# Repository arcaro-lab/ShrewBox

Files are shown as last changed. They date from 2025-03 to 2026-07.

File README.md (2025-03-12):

# ShrewBox: Modular Behavior Box for Tree Shrew and Other Small Animal Experiments

## Overview
We developed a low-cost, customizable behavior box designed for conducting animal experiments, particularly in tree shrews and other small animals. This modular platform allows precise control over stimulus presentation and reward delivery while animals maintain access to their home cage. It expands the methodological toolkit for investigating complex behaviors in a controlled yet naturalistic environment.

## Features
- **Precision Reward Delivery**: Stepper motors provide fine control (0.11° step rotation) of reward amounts with individual channel control, reducing wear and tear. These are downsized versions of the wonderful pumps developed by the Pachter Lab (https://github.com/pachterlab/pegasus).
- **Adjustable Visual Display**: Can accomodate 14"-15" monitors allowing for  adjustable viewing angles and distances ensure optimal stimulus presentation.
- **Capacitive Touch Pads**: Enables animals to indicate choices while maintaining gaze at the screen, allowing precise tracking of body position.
- **Compact and Integrated**: Raspberry Pi 4 replaces external computers, reducing footprint and minimizing the number of Arduinos and wires. All components are mounted directly on the box.
- **Customizable Box Panels**: Laser-cut and 3D-printable components simplify assembly while enabling modular expansion.
- **Scalability**: Daisy chain multiple behavior boxes to the same power source for simultaneous experiments.
- **Open-Source Experiment Control**: Runs on Python-based PsychoPy, making it accessible and customizable.
- **Integrated Weight Monitoring**: Onboard weight scale for tracking animal weight in real time.

## Assembly and Usage
We are currently developing detailed written instructions and instructional videos for assembling and using the behavior box. These will be available in this repository soon. In the meantime, groups interested in the behavior box should reach out to us directly for more information.

Currently, this repository provides:
- 3D files for 3D printing
- Files for laser-cut panels
- Bill of materials
- Source code for the capacitive touch sensor
- Source code for controlling Arduinos that interface with the stepper motor and weight sensors

## Photo
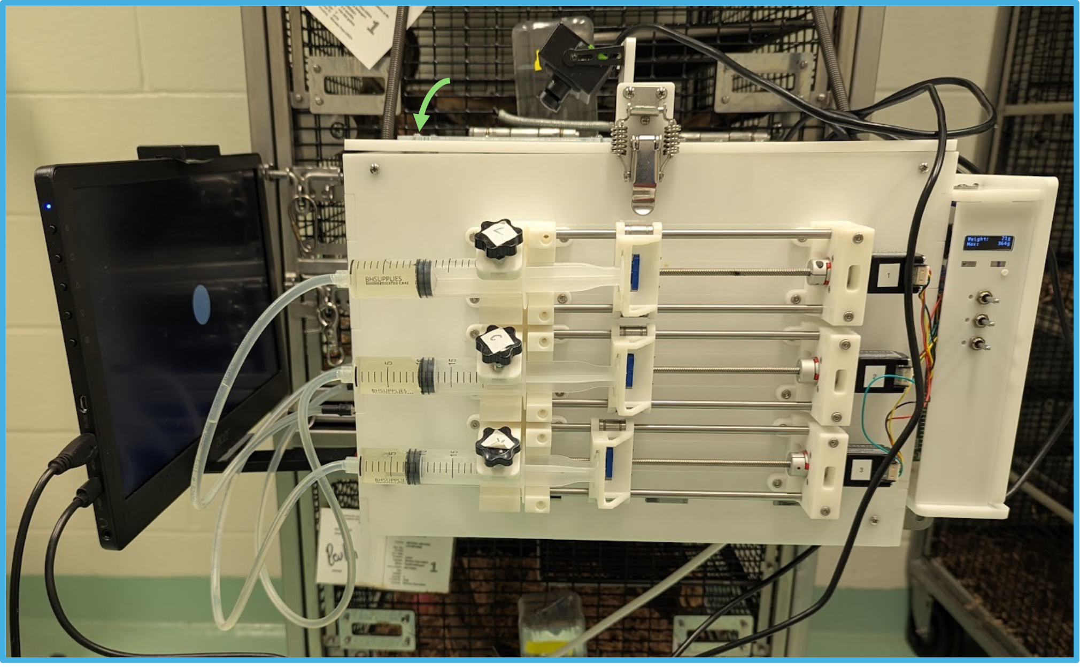
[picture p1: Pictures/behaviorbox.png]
Behavior Box


## Contributions
This project is open-source, and we welcome contributions! If you have improvements or modifications, feel free to submit a pull request or open an issue.

---
For inquiries, please contact the [Arcaro Lab](https://arcarolab.com).

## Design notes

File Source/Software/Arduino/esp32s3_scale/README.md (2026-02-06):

# ESP32-S3 Digital Scale (NAU7802 + TFT Feather)

This project is an update for a legacy  
**Teensy 3.2 + TeensyView + load cell** digital scale, rewritten for the:

- **Adafruit TFT Feather ESP32-S3 (Reverse)**
- **NAU7802 24-bit ADC**
- **1 kg load cell**

It reads the load cell via the NAU7802, converts the value to **grams**, displays
the result on the built‑in TFT, and streams measurements over **USB Serial**.
A hardware button on **D0** is used for **tare**.

---

## Features

- 📏 24‑bit load cell reading via **NAU7802**
- ⚖️ Linear calibration: tare offset + scale factor
- 📺 Live weight + max weight display on TFT
- 🧮 Exponential smoothing (similar feel to the Teensy implementation)
- 🔘 **D1 button** for tare (INPUT_PULLDOWM, active‑high)
- 💻 USB Serial output for logging
- ⌨️ Serial commands compatible with the Teensy workflow

---

## Hardware

### Required
- Adafruit **TFT Feather ESP32‑S3 (Reverse)**
- **NAU7802** load cell amplifier
- 1 kg (or similar) load cell (Wheatstone bridge)

### Connections
| Signal | ESP32‑S3 Feather |
|---|---|
| NAU7802 SDA | SDA |
| NAU7802 SCL | SCL |
| NAU7802 VCC | 3V |
| NAU7802 GND | GND |
| Tare Button | D1 → GND |

> The NAU7802 uses I²C. No extra pins are required.

---

## Software Dependencies

Install the following libraries via **Arduino Library Manager**:

- **Adafruit NAU7802**
- **Adafruit GFX Library**
- **Adafruit ST7789**
- **Adafruit BusIO**

Board package:
- **Adafruit ESP32 Boards**  
  (select *Adafruit Feather ESP32‑S3 TFT*)

---

## Serial Commands

| Command | Action |
|---|---|
| `t` | Tare (zero the scale) |
| `s` | Start / stop streaming |

Baud rate: **115200**

---

## Calibration (Important)

Calibration is intentionally simple.

1. Upload the sketch
2. Open **Serial Monitor**
3. Ensure the scale is empty
4. Press **D1** (or send `t`) to tare
5. Place a **known weight** (e.g. 100 g)
6. Observe the printed values:
   ```
   RAW=xxxxx, TARE=yyyyy
   ```
7. Compute:
   ```
   CAL_G_PER_COUNT = known_grams / (RAW - TARE)
   ```
8. Edit the sketch:
   ```cpp
   static float CAL_G_PER_COUNT = 0.00012345;
   ```
9. Re-upload

---

## Display

The TFT shows:
- **Current weight (g)**
- **Maximum weight recorded**
- Tare offset and calibration factor (debug)

Update rate: ~4 Hz (configurable)

---

## Notes

- If readings appear inverted, either:
  - swap the load cell signal wires, or
  - leave wiring as-is (the code displays absolute weight)
- The smoothing factor can be adjusted:
  ```cpp
  static const float EMA_ALPHA = 0.20f;
  ```
- Power is fully USB-based

---

## License

MIT License  
Use freely for research, teaching, and lab instrumentation.

---

## Acknowledgments

- Adafruit NAU7802 driver
- Original Teensy-based scale implementation

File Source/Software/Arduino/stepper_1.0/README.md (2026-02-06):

# 3-Channel Stepper Motor Controller (TMC2209 + Serial)

This project implements a **3-stepper-motor controller** using **TMC2209 step/dir drivers**, controlled either by **physical toggle switches** or by **serial commands** over USB.

It is designed for **simple, reliable lab use**, supporting both manual jogging and scripted motion from MATLAB, Python, or a serial terminal.

---

## Features

- Control **3 independent stepper motors**
- Dual control modes:
  - **Manual toggle switches** (LEFT / RIGHT per motor)
  - **Serial control** over USB
- Simple human-readable command format  
  (`S1,0,100`, `S2,1,200,400`)
- Compatible with **TMC2209 in STEP/DIR mode**
- Deterministic blocking motion (easy to reason about)

---

## Hardware Assumptions

- Microcontroller with USB serial (nRF52 / TinyUSB compatible)
- Stepper drivers: **TMC2209** (standalone STEP/DIR mode)
- Enable pin is **active-LOW**
- Toggle switches wired to **GND**, using `INPUT_PULLUP`

---

## Pin Mapping

### Stepper Drivers

| Motor | DIR | STEP | EN |
|---:|----:|-----:|---:|
| S1 | D4 | D5 | D6 |
| S2 | D2 | D13 | D3 |
| S3 | D0 | D11 | D1 |

### Toggle Switches

| Motor | LEFT | RIGHT |
|---:|-----:|---:|
| S1 | D19 | D7 |
| S2 | D18 | D8 |
| S3 | D10 | D9 |

Switch inputs are **active LOW**.

---

## Motion Parameters

Defined in firmware:

```cpp
int defaultSteps = 100;   // steps per button press
int defaultSpUs  = 400;  // microseconds HIGH + LOW per step
```

- `sp_us = 400` → ~1250 steps/sec
- Smaller `sp_us` → faster motion

Each step pulse:
- HIGH for `sp_us`
- LOW  for `sp_us`

---

## Serial Interface

- **Baud rate:** `57600`
- ASCII, line-based commands
- Commands are **case-insensitive**
- Newline (`\n`) or carriage return (`\r`) ends a command

---

## Serial Command Format

### Basic Move

```
S<motor>,<dir>,<steps>
```

Example:
```
S1,0,100
```

Meaning:
- Motor 1
- Direction = 0 (clockwise)
- 100 steps
- Uses default speed

---

### Move With Speed Control

```
S<motor>,<dir>,<steps>,<sp_us>
```

Example:
```
S2,1,200,300
```

Meaning:
- Motor 2
- Direction = 1 (anti-clockwise)
- 200 steps
- 300 µs HIGH + 300 µs LOW per step

---

## Direction Convention

| Value | Meaning | DIR pin |
|-----:|---|---|
| `0` | Clockwise (CW) | LOW |
| `1` | Anti-clockwise (CCW) | HIGH |

> If your mechanical direction is reversed, swap `HIGH` / `LOW` in `setDir()`.

---

## Manual Toggle Switch Operation

- Press **LEFT** → motor moves CCW
- Press **RIGHT** → motor moves CW
- Each press moves `defaultSteps` steps
- Serial commands remain active while using buttons

---

## Example Usage

### Serial Terminal
```
S1,0,100
S2,1,500,250
S3,0,1000
```

### Python
```python
import serial
ser = serial.Serial("/dev/ttyACM0", 57600)
ser.write(b"S1,0,100\n")
```

### MATLAB
```matlab
s = serialport("/dev/ttyACM0",57600);
writeline(s,"S2,1,200,400");
```

---

## Design Notes

- Motion is **blocking**
  - Simple, predictable behavior
  - Motors do not move simultaneously
- No acceleration or ramping
- No absolute position tracking (open-loop)
- Well suited for:
  - Calibration rigs
  - Syringe pumps
  - Optical positioning
  - Behavioral experiment hardware

---

## File List

- `stepper_1.0.ino` — main firmware
- `README.md` — documentation

---

## Future Improvements (Optional)

- Non-blocking motion (simultaneous motors)
- Acceleration profiles
- Homing and limit switches
- Absolute positioning
- Command queueing
- Enable/disable motors via serial

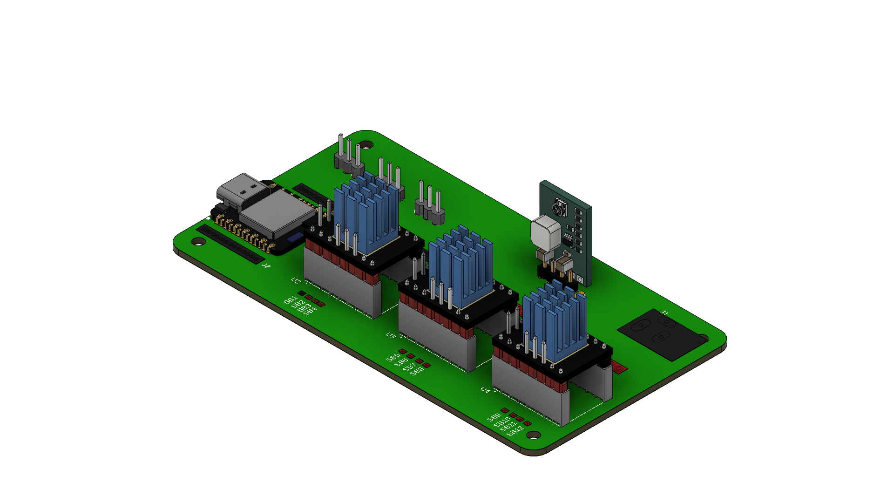
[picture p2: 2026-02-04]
Source/Electronic/StepperDriver/StepperDriverBoard.png

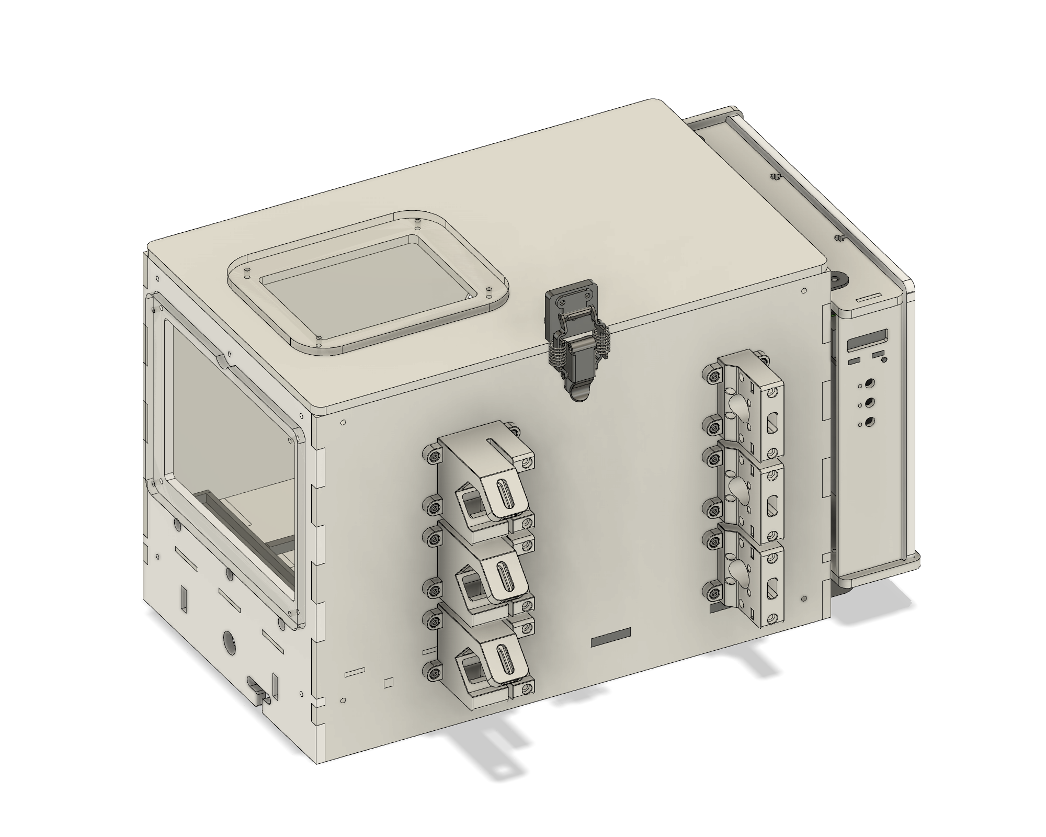
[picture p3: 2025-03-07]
Pictures/renderView01.png

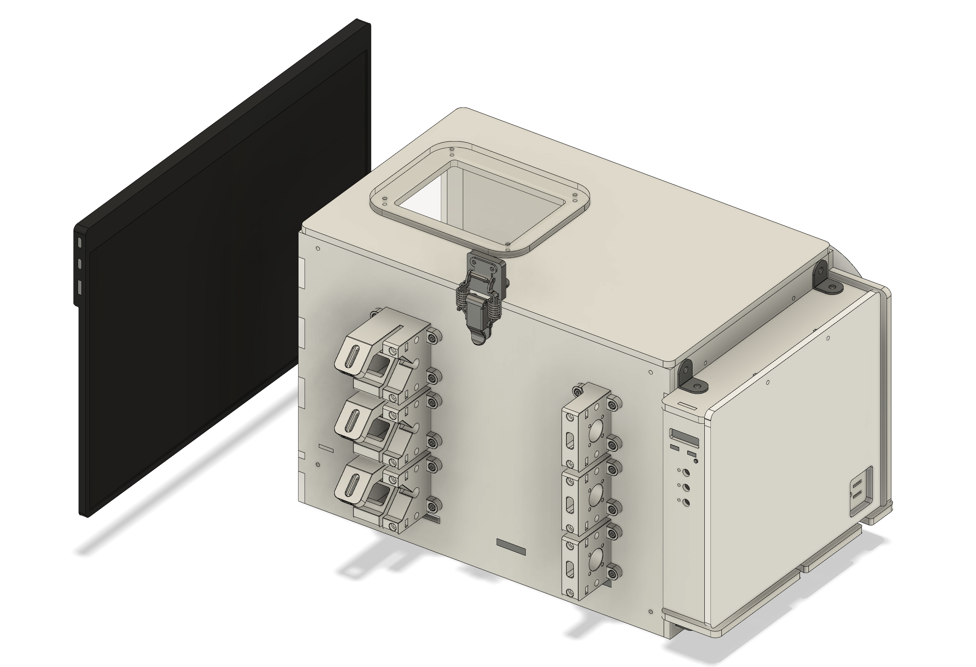
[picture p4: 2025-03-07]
Pictures/renderView02.png

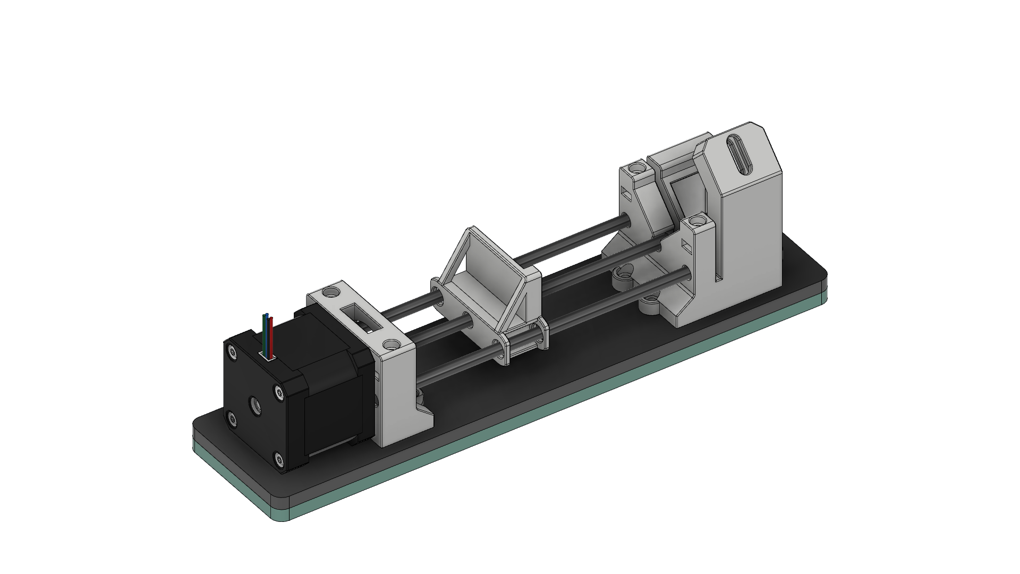
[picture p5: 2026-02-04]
Pictures/SP1002V01-120mm v3.png

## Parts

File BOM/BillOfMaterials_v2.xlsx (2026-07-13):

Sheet: BOM
Electronics | Controller and Power
Item | Description | Qty | Unit Price | Part Number | Cost | Supplier | Link
1 | RASPBERRY PI 4 B 4GB | 1 | 55 | 2648-SC0194(9)-ND | 55 | Digikey | https://www.digikey.com/en/products/detail/raspberry-pi/RASPBERRY-PI-4B-4GB/10258781
2 | ARDUINO NANO ATMEGA328 EVAL BRD | 1 | 24.9 | 1050-1001-ND | 24.9 | Digikey | https://www.digikey.com/en/products/detail/arduino/A000005/2638989
3 | 5 Ft Small Power Strip with 3 Outlets and 3 USB Ports(2 USB C) | 1 | 11.99 | B0CS6FMXH5 | 11.99 | Amazon | https://www.amazon.com/gp/product/B0CS6FMXH5
4 | USB to Mini USB Cable (for Arduino NANO) | 1 | 7.99 | B003WV5DME | 7.99 | Amazon | https://www.amazon.com/StarTech-com-6in-Mini-USB-Cable/dp/B003WV5DME
5 | 0.5ft USB A to USB C Cable (For Power Raspberry pi and Teensy) | 1 | 6.99 | B0DPF8TFC9 | 6.99 | Amazon | https://www.amazon.com/Charging-Braided-iPhone-Samsung-Galaxy/dp/B0DPF8TFC9?th=1
6 | Screen Desk Holder Metal Stand 16 Inch | 1 | 31.99 | B0CTCNC1P1 | 31.99 | Amazon | https://www.amazon.com/AiFeelife-Portable-Universal-Expandable-Adjustable/dp/B0CTCNC1P1
7 | Acer 16PM1Q Bbmiuux 15.6" Full HD 1920 x 1080 IPS Portable Monitor | 1 | 89.99 | B0CJQ841VW | 89.99 | Amazon | https://www.amazon.com/AOPEN-Business-Portable-External-Speakers/dp/B0CJQ841VW?th=1
Electronics | Syringe Pump
Item | Description | Qty | Unit Price | Part Number | Cost | Supplier | Link
1 | STEPPERONLINE Stepper Motor Nema 17 Bipolar 40mm 64oz.in(45Ncm) 2A, 17HS16-2004S | 3 | 12.99 | B00PNEQI7W | 38.97 | Amazon | https://www.amazon.com/Stepper-Motor-Bipolar-64oz-Printer/dp/B00PNEQI7W
2 | TMC2209 V2.0 Stepper Motor Driver (pack of 5) | 1 | 19.88 | B09BK57KNY | 19.88 | Amazon | https://www.amazon.com/Teyleten-Robot-TMC2209-Stepper-StepStick/dp/B09BK57KNY
3 | Toggle Switch SPDT Panel Mount | 1 | 6.89 | B079JG2YSM | 6.89 | Amazon | https://www.amazon.com/HiLetgo-Terminals-Position-Toggle-MTS-103/dp/B079JG2YSM
4 | Custom PCB | 1 | 6.99 | B0DBZ1BXFZ | 6.99 | Amazon | https://www.amazon.com/Rindion-Compatible-Prototype-Electronics-Soldering/dp/B0DBZ1BXFZ
5 | Breadboard-Friendly 2.1mm PCB Mounting Female DC Power Barrel Jack (10 PCS) | 1 | 8.99 | B09XH1XJZT | 8.99 | Amazon | https://www.amazon.com/California-JOS-Breadboard-Friendly-Mounting-Female/dp/B09XH1XJZT/?th=1
6 | 40PCS 2.54MM Male and Female Header Pin | 1 | 7.49 | B08DVGCTKT | 7.49 | Amazon | https://www.amazon.com/2-54MM-Breakaway-Connector-Arduino-Prototype/dp/B08DVGCTKT/
7 | Seeed Studio XIAO nRF52840 Plus | 1 | 10.4 | 1597-102010672-ND | 10.4 | Digikey | https://www.digikey.com/en/products/detail/seeed-technology-co-ltd/102010672/26553862
Electronics | Scale
Item | Description | Qty | Unit Price | Part Number | Cost | Supplier | Link
1 | ESP32-S3 REVERSE TFT FEATHER | 1 | 24.95 | 1528-5691-ND | 24.95 | Digikey | https://www.digikey.com/en/products/detail/adafruit-industries-llc/5691/18627502
2 | NAU7802 Analog to Digital Converter (ADC) Data Acquisition | 1 | 17.95 | 1528-4538-ND | 17.95 | Digikey | https://www.digikey.com/en/products/detail/adafruit-industries-llc/4538/16584123
3 | STRAIN GAUGE LOAD CELL - 4 WIRES - 1KG | 1 | 3.95 | 1528-4540-ND | 3.95 | Digikey | https://www.digikey.com/en/products/detail/adafruit-industries-llc/4540/12323569
4 | 4 Position Cable Assembly Rectangular Socket to Socket 0.164' (50.00mm, 1.97") | 1 | 0.95 | 1528-4399-ND | 0.95 | Digikey | https://www.digikey.com/en/products/detail/adafruit-industries-llc/4399/10824268
Electronics | Capacitive Sensor
Item | Description | Qty | Unit Price | Part Number | Cost | Supplier | Link
1 | SEEEDSTUDIO XIAO SAMD21 NO HDRS | 1 | 5.4 | 1597-102010328-ND | 5.4 | Digikey | https://www.digikey.com/en/products/detail/seeed-technology-co-ltd/102010328/11506471
2 | Custom made PCB (use gerber file from the SOURCE folder) | 1 |  | Custom
Mechnical | ShrewBox
Item | Description | Qty | Unit Price | Part Number |  | Supplier | Link
 | Cast Acrylic Sheet, 12"x24"x1/4" White | 7 | 21.13 | 8505K755 | 147.91 | McMaster | https://www.mcmaster.com/8505K755-8505K927/
 | Clear Scratch- and UV-Resistant Acrylic Sheet, 12" x 12" x 1/16" | 1 | 5.14 | 8589K11 | 5.14 | McMaster | https://www.mcmaster.com/8589K11/
 | Cast Acrylic Sheet, 12" x 12" x 1/8", White | 1 | 9.65 |  | 9.65 | McMaster | https://www.mcmaster.com/8505K741-8505K117/
 | Cast Acrylic Sheet, 12" x 12" x 1/8", Green | 1 | 9.65 | 8505K741 | 9.65 | McMaster | https://www.mcmaster.com/8505K741-8505K115/
 | L Bracket Corner Brace (40 pcs) | 1 | 9.99 | B09TP2S2WY | 9.99 | Amazon | https://www.amazon.com/Bracket-Brackets-Furniture-Cabinet-20mmx20mm/dp/B09TP2S2WY
 | Spring hasp Toolbox Toggle latches Lock (6 pcs) | 1 | 15.99 | B0CNZSB7JR | 15.99 | Amazon | https://www.amazon.com/Toolbox-latches-Lock%EF%BC%8CStainless-SteelToolbox-Compression/dp/B0CNZSB7JR
 | Door Hinges | 2 | 14.99 | B0882STR1H | 29.98 | Amazon | https://www.amazon.com/Commercial-Residential-Stainless-Steel-Bearing-2pack/dp/B0882STR1H
 | Passivated 18-8 Stainless Steel Pan Head Phillips Screw4-40 Thread, 3/8" Long (100 pcs) | 1 | 6.2 | 91772A108 | 6.2 | McMaster | https://www.mcmaster.com/91772A108/
 | Passivated 18-8 Stainless Steel Pan Head Phillips Screw4-40 Thread, 1/2" Long (100 pcs) | 1 | 6.41 | 91772A110 | 6.41 | McMaster | https://www.mcmaster.com/91772A110/
 | 18-8 Stainless Steel Hex Nut 4-40 Thread Size (100 pcs) | 1 | 3.69 | 91841A005 | 3.69 | McMaster | https://www.mcmaster.com/91841A005/
Mechnical | SyringePump (New, Larger Stepper NEMA 17, short rail)
Item | Description | Qty | Unit Price | Part Number |  | Supplier | Link
 | Fully Threaded Rod, M5-0.8 Thread Pitch, 100mm Length 304 Stainless Steel | 1 | 9.49 | B096KXQTYQ | 9.49 | Amazon | https://www.amazon.com/dp/B096KXQTYQ
 | 304 Stainless Steel Round Rods, 5mm x 120mm Solid Shaft Rods | 1 | 6.69 | B0DPH23KP1 |  | Amazon | https://www.amazon.com/dp/B0DPH23KP1
 | LM5UU Linear Ball Bearings, 5mm Bore Dia, 10mm OD,15mm Length | 1 | 17.09 | B0CR41WZG2 |  | Amazon | https://www.amazon.com/dp/B0CR41WZG2
 | Flexible Couplings 5mm to 5mm | 1 | 9.99 | B07M5Q7HTV |  |  | https://www.amazon.com/dp/B07M5Q7HTV
 | Hex Nuts, M5-0.8 Stainless Steel 304 (18-8) Hex Nut | 1 | 6.99 | B0BLBLBP93 |  |  | https://www.amazon.com/dp/B0BLBLBP93
 | M3 Hex Socket Head Cap Screws Assortment Kit, M3x 6/8/10/12/16/20/25/30mm | 1 | 8.99 | B0FHHL1W3X |  |  | https://www.amazon.com/Assortment-Internal-Washers-Stainless-Threaded/dp/B0FHHL1W3X/
 | M5 x 20mm Metric Male Thread Knurled Clamping Knobs (8 pcs) (For secure syringe) | 1 | 12.29 | B07KPGBXFC | 12.29 | Amazon | https://www.amazon.com/uxcell-Thread-Knurled-Clamping-Knobs/dp/B07KPGBXFC/?th=1
 | 3D Printed Parts (3xSyringe Pump, Circular Entrance) | 1 |  | Custom | 0
 |  |  |  | Total | 648.05

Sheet: AcrylicSheet
Name | Thickness (inch) | Color | Quantity
FrontPanel | 1/4 | White | 1
LeftPanel | 1/4 | White | 1
FrontWindow | 1/8 or 1/4 | Clear | 1
RightPanel | 1/4 | White | 1
TopCover | 1/4 | White | 1
TopWindow | 1/8 or 1/4 | Clear | 1
BackPanel | 1/4 | White | 1
EBoxCover | 1/4 | White | 1
EBoxFrontPanel | 1/8 | White | 1
EBoxTopPanel | 1/4 | White | 1
EBoxBottomPanel | 1/4 | White | 1
WeightFloor | 1/8 | Green | 1
BottomPanelA | 1/8 | White | 1
BottomPanelB | 1/4 | White | 1
BottomPanelConnector | 1/4 | White | 1
BottomGuide | 1/4 | White | 2
EBoxSepA | 1/8 | White | 1
EBocSepB | 1/4 | White | 1
EBoxSepC | 1/4 | White | 1
GuardPanel | 1/8 | White | 1
GuageSpacer | 1/4 | White | 1
LockStand | 1/4 | White | 1
CameraStand | 1/4 | White | 1
JuiceTrayBottom | 1/8 | Clear | 1
JuiceTraySideA | 1/8 | Clear | 2
JuiceTraySideB | 1/8 | Clear | 2

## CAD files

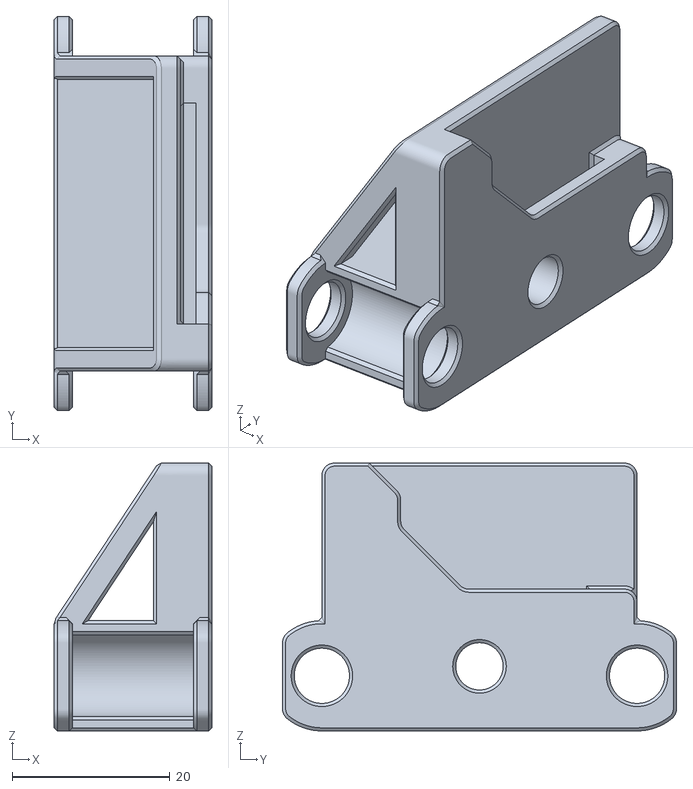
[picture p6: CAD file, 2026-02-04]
3DFiles/Carriage.stl
20.0 x 50.0 x 34.0

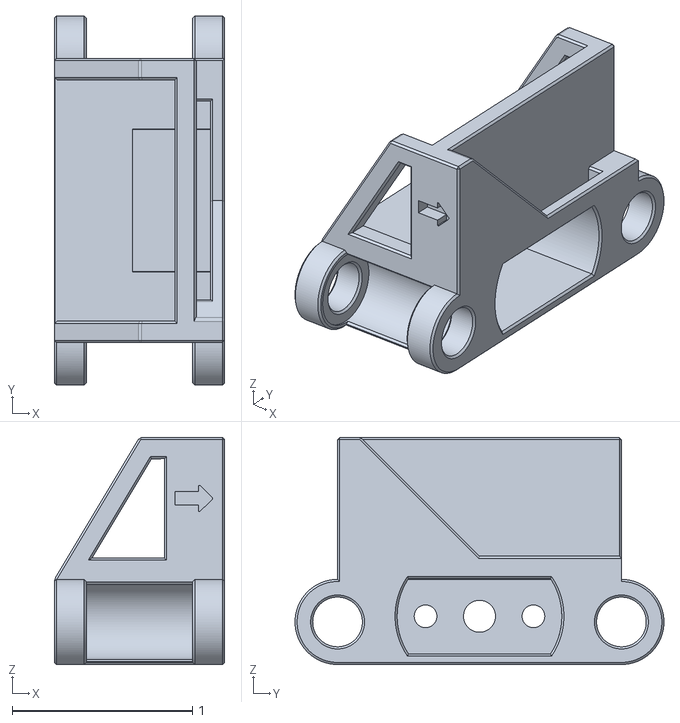
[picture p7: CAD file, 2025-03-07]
3DFiles/v1/Carriage.stl
0.945 x 2.05 x 1.26

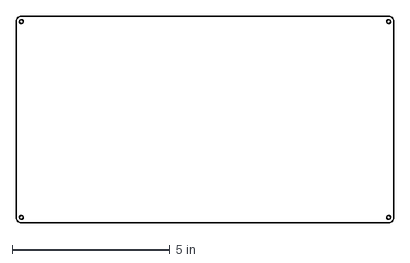
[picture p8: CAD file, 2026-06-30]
LaserCutPanel/GuardPanel.dxf
12.0 x 6.54 in

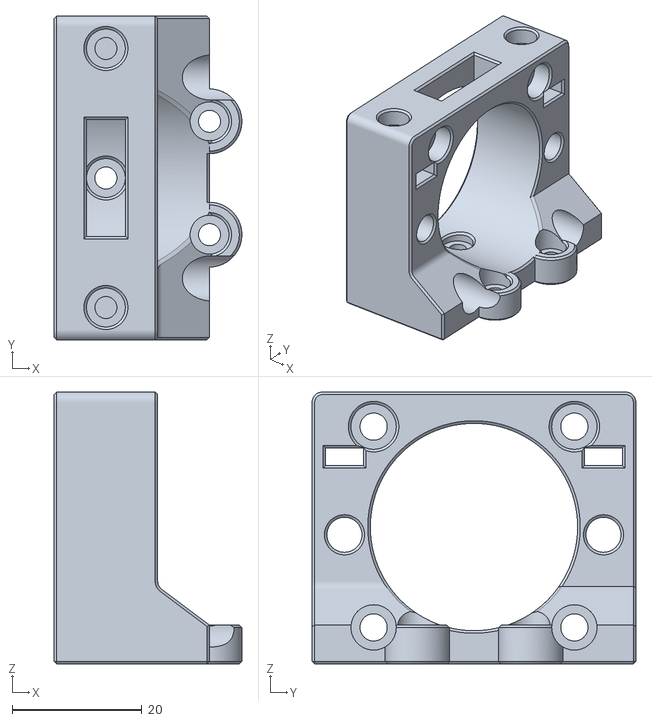
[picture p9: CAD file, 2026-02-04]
3DFiles/stepperBase.stl
29.0 x 50.0 x 42.0

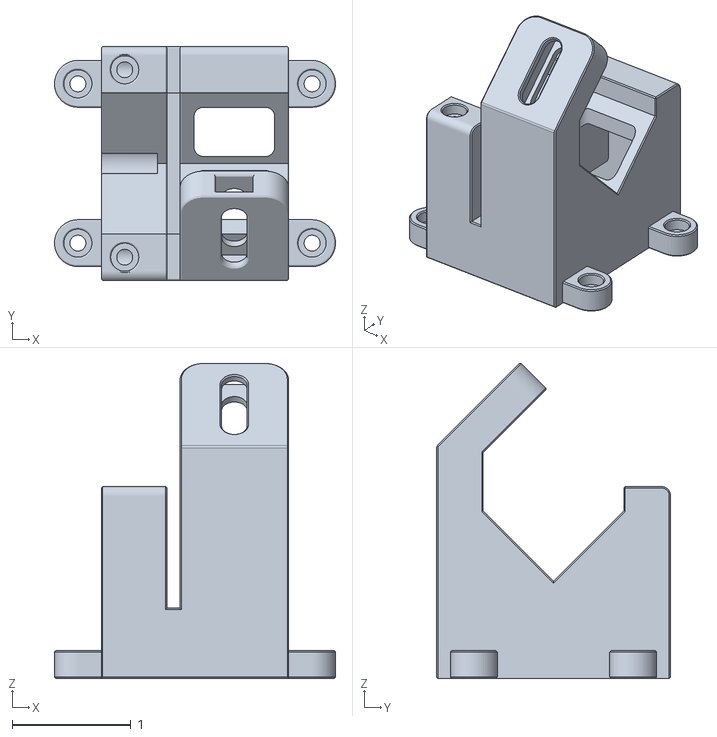
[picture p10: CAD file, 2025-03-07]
3DFiles/v1/SyringePumpA.stl
2.36 x 1.97 x 2.65

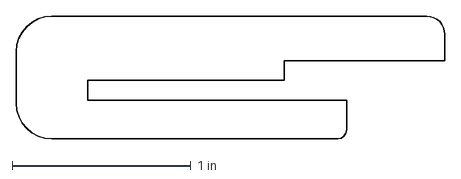
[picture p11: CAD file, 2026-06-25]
LaserCutPanel/BottomGuide.dxf
2.40 x 0.687 in

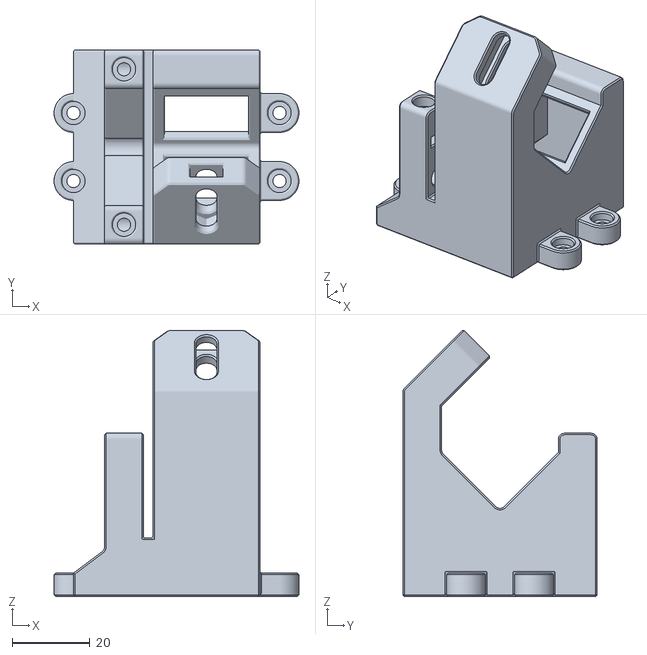
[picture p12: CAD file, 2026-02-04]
3DFiles/syringeBase.stl
63.0 x 50.0 x 68.4

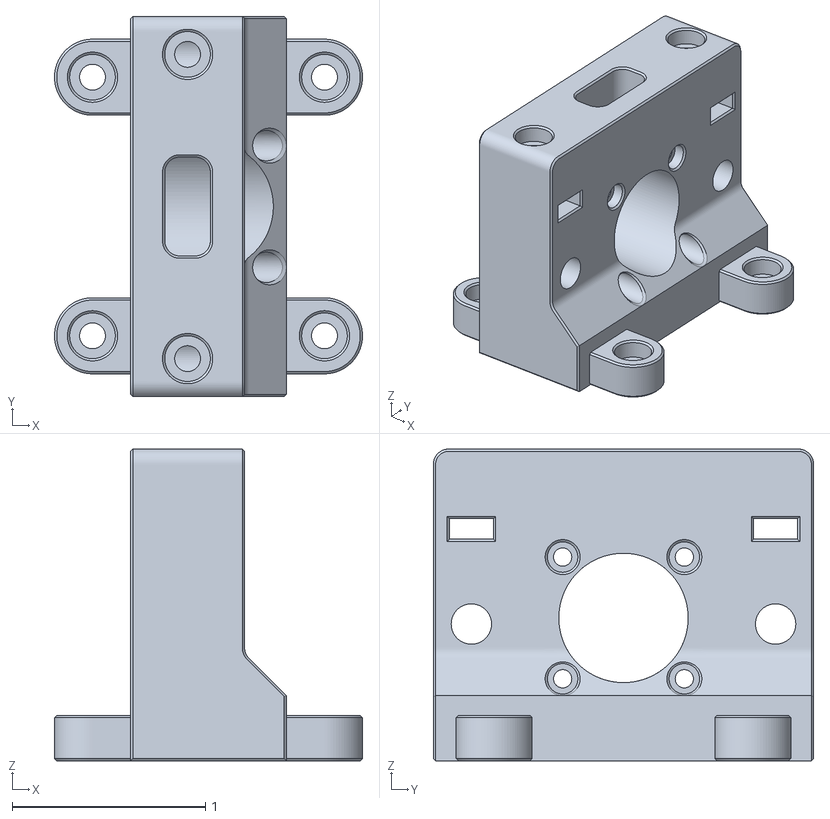
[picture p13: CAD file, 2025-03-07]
3DFiles/v1/SyringePumpB.stl
1.59 x 1.97 x 1.61

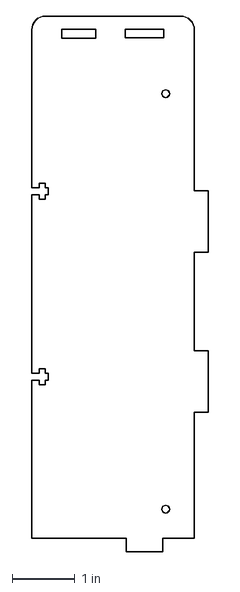
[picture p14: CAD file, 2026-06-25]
LaserCutPanel/EBoxTopPanel.dxf
2.82 x 8.56 in

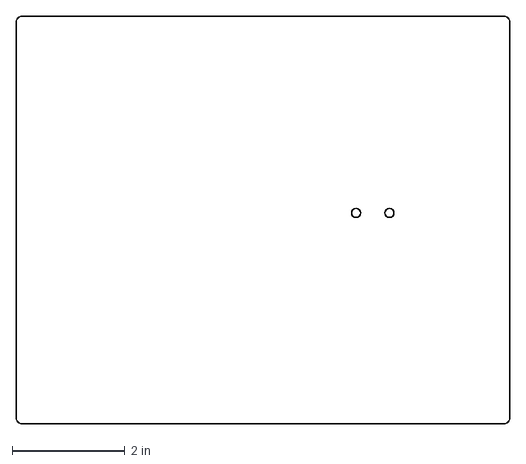
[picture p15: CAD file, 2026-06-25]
LaserCutPanel/WeightFloor.dxf
8.74 x 7.21 in

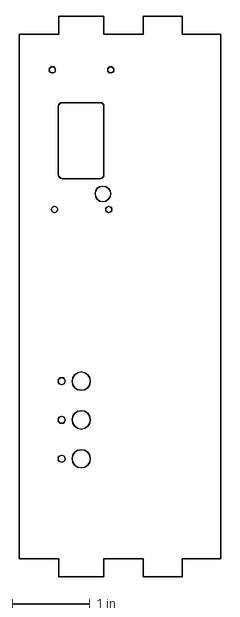
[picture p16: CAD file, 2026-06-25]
LaserCutPanel/EBoxFrontPanel.dxf
2.60 x 7.22 in

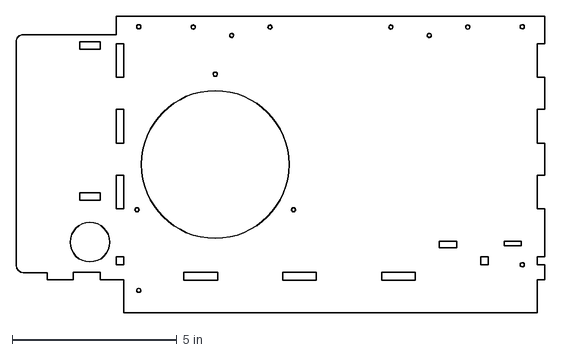
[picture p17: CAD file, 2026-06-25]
LaserCutPanel/LeftPanel.dxf
16.0 x 9.00 in

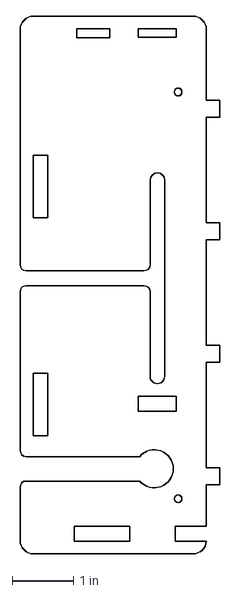
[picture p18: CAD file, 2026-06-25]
LaserCutPanel/EBoxBottomPanel.dxf
3.26 x 8.78 in

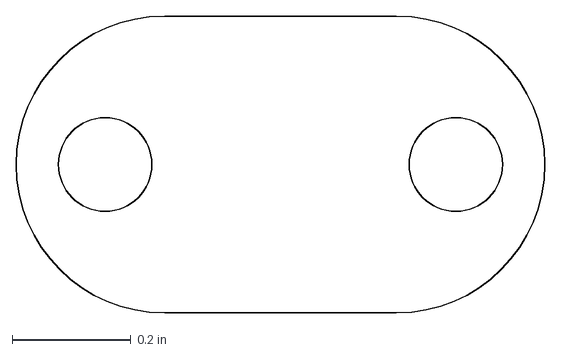
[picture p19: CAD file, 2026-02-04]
LaserCutPanel/GuageSpacer.dxf
0.891 x 0.5 in

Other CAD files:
LaserCutPanel/TopWindow.dxf
LaserCutPanel/BottomPanelConnector.dxf
LaserCutPanel/FrontPanel.dxf
LaserCutPanel/EBoxCover.dxf
LaserCutPanel/BackPanel.dxf
LaserCutPanel/BottomPanelA.dxf
LaserCutPanel/BottomPanelB.dxf
LaserCutPanel/CameraStand.dxf
LaserCutPanel/EBocSepB.dxf
LaserCutPanel/EBoxSepA.dxf
LaserCutPanel/EBoxSepB.dxf
LaserCutPanel/EBoxSepC.dxf
LaserCutPanel/FrontWindow.dxf
LaserCutPanel/JuiceTrayBottom.dxf
LaserCutPanel/JuiceTraySideA.dxf
LaserCutPanel/JuiceTraySideB.dxf
LaserCutPanel/LockStand.dxf
LaserCutPanel/RightPanel.dxf
LaserCutPanel/TopCover.dxf

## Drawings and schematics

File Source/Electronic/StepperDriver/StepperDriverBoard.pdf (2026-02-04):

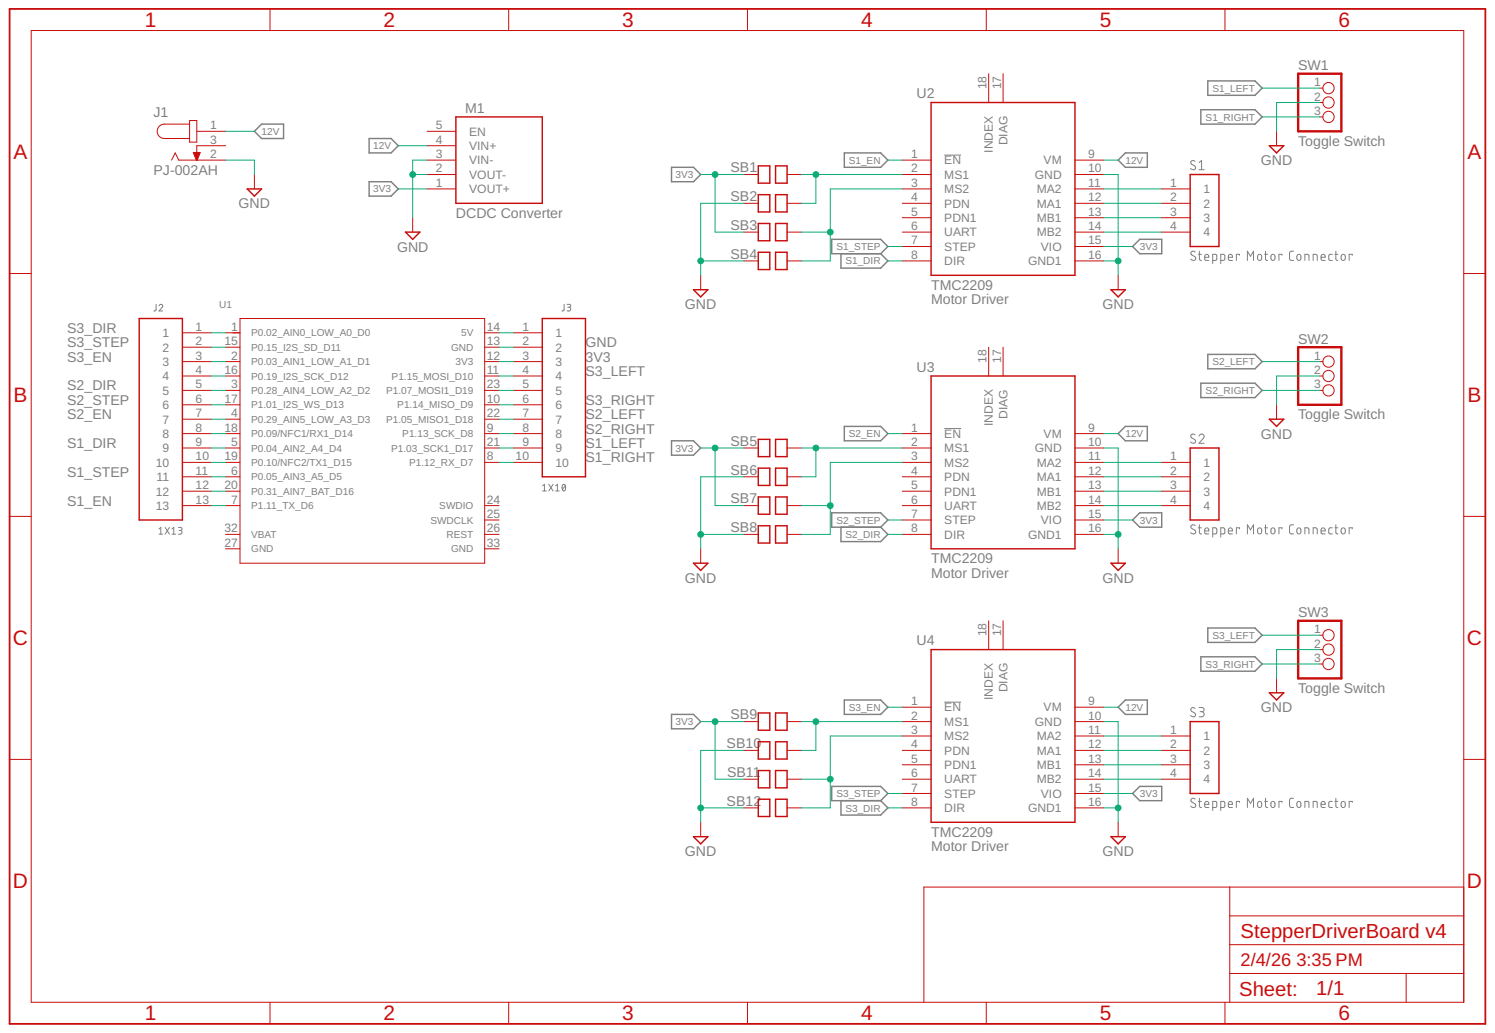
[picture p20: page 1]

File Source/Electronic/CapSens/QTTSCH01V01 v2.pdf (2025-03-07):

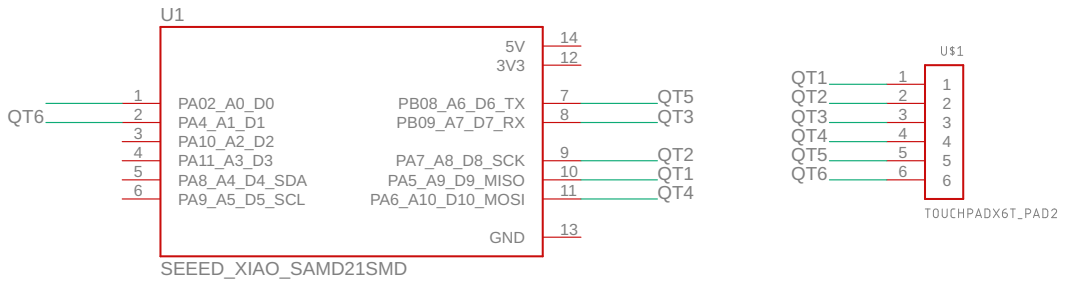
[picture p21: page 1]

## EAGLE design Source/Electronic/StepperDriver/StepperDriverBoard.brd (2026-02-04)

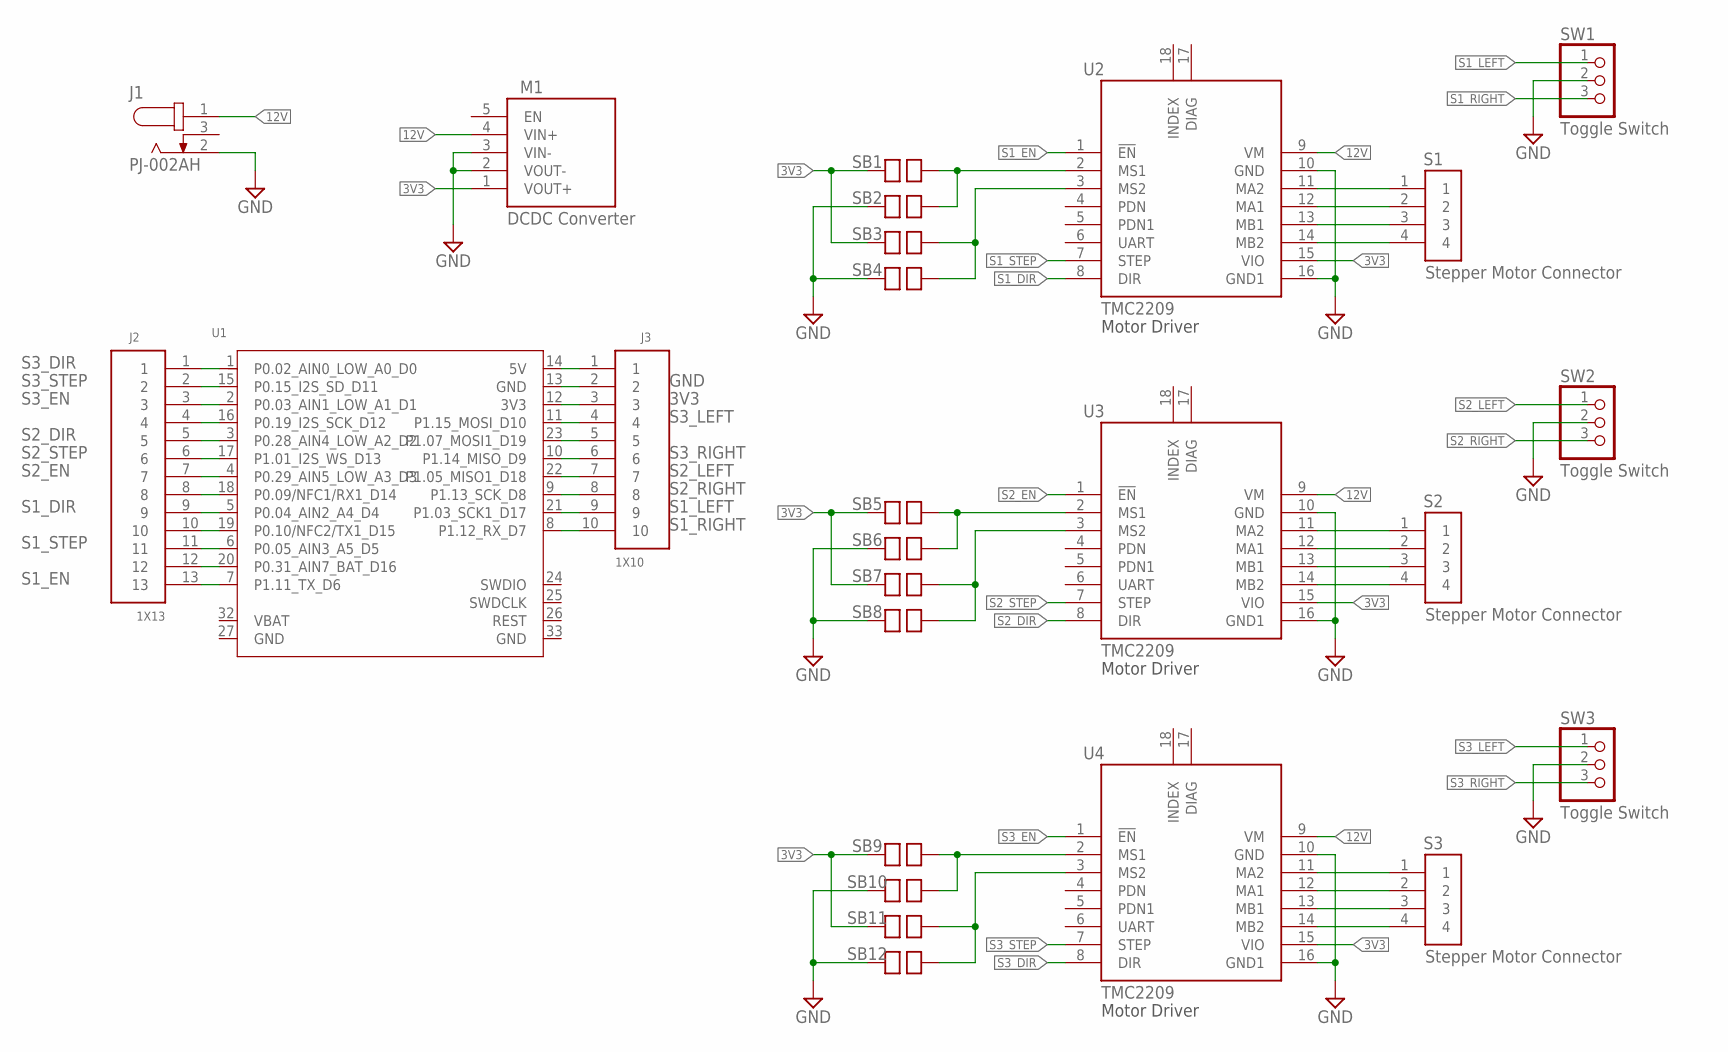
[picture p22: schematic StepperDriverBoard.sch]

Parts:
J1: PJ-002AH; CUI_PJ-002AH
J2: 1X13; 1X13-127MM
J3: 1X10; 1X10-127MM
M1: DCDC Converter; DROK_5V
S1, S2, S3: Stepper Motor Connector; 1X04-BIG
SB1, SB2, SB3, SB4, SB5, SB6, SB7, SB8, SB9, SB10, SB11, SB12: JUMPERP; JUMPER
SW1, SW2, SW3: Toggle Switch; 1X03
U1: XIAO-NRF52840_PLUS_SMDXIAO-NRF52840_PLUS; XIAO-NRF52840_PLUS_SMD
U2, U3, U4: TMC2209; MODULE_TMC2209_PINS

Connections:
3V3: J3.3, M1.1 (VOUT+), SB1.1, SB3.1, SB5.1, SB7.1, SB9.1, SB11.1, U1.12 (3V3), U2.15 (VIO), U3.15 (VIO), U4.15 (VIO)
12V: J1.1, M1.4 (VIN+), U2.9 (VM), U3.9 (VM), U4.9 (VM)
GND: J1.2, J3.2, M1.2 (VOUT-), M1.3 (VIN-), SB2.1, SB4.1, SB6.1, SB8.1, SB10.1, SB12.1, SW1.2, SW2.2, SW3.2, U1.13 (GND), U2.10 (GND), U2.16 (GND1), U3.10 (GND), U3.16 (GND1), U4.10 (GND), U4.16 (GND1)
unnamed: S2.1, U3.11 (MA2)
unnamed: S1.1, U2.11 (MA2)
unnamed: S1.2, U2.12 (MA1)
unnamed: S1.3, U2.13 (MB1)
unnamed: S1.4, U2.14 (MB2)
unnamed: SB1.2, SB2.2, U2.2 (MS1)
unnamed: SB3.2, SB4.2, U2.3 (MS2)
unnamed: S2.2, U3.12 (MA1)
unnamed: S2.3, U3.13 (MB1)
unnamed: S2.4, U3.14 (MB2)
unnamed: SB5.2, SB6.2, U3.2 (MS1)
unnamed: SB7.2, SB8.2, U3.3 (MS2)
unnamed: S3.1, U4.11 (MA2)
unnamed: S3.2, U4.12 (MA1)
unnamed: S3.3, U4.13 (MB1)
unnamed: S3.4, U4.14 (MB2)
unnamed: SB9.2, SB10.2, U4.2 (MS1)
unnamed: SB11.2, SB12.2, U4.3 (MS2)
unnamed: J2.10, U1.19 (P0.10/NFC2/TX1_D15)
unnamed: J2.8, U1.18 (P0.09/NFC1/RX1_D14)
unnamed: J2.12, U1.20 (P0.31_AIN7_BAT_D16)
unnamed: J2.4, U1.16 (P0.19_I2S_SCK_D12)
unnamed: J3.1, U1.14 (5V)
unnamed: J3.5, U1.23 (P1.07_MOSI1_D19)
S1_DIR: J2.9, U1.5 (P0.04_AIN2_A4_D4), U2.8 (DIR)
S1_EN: J2.13, U1.7 (P1.11_TX_D6), U2.1 (!EN)
S1_LEFT: J3.9, SW1.1, U1.21 (P1.03_SCK1_D17)
S1_RIGHT: J3.10, SW1.3, U1.8 (P1.12_RX_D7)
S1_STEP: J2.11, U1.6 (P0.05_AIN3_A5_D5), U2.7 (STEP)
S2_DIR: J2.5, U1.3 (P0.28_AIN4_LOW_A2_D2), U3.8 (DIR)
S2_EN: J2.7, U1.4 (P0.29_AIN5_LOW_A3_D3), U3.1 (!EN)
S2_LEFT: J3.7, SW2.1, U1.22 (P1.05_MISO1_D18)
S2_RIGHT: J3.8, SW2.3, U1.9 (P1.13_SCK_D8)
S2_STEP: J2.6, U1.17 (P1.01_I2S_WS_D13), U3.7 (STEP)
S3_DIR: J2.1, U1.1 (P0.02_AIN0_LOW_A0_D0), U4.8 (DIR)
S3_EN: J2.3, U1.2 (P0.03_AIN1_LOW_A1_D1), U4.1 (!EN)
S3_LEFT: J3.4, SW3.1, U1.11 (P1.15_MOSI_D10)
S3_RIGHT: J3.6, SW3.3, U1.10 (P1.14_MISO_D9)
S3_STEP: J2.2, U1.15 (P0.15_I2S_SD_D11), U4.7 (STEP)

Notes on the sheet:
Motor Driver

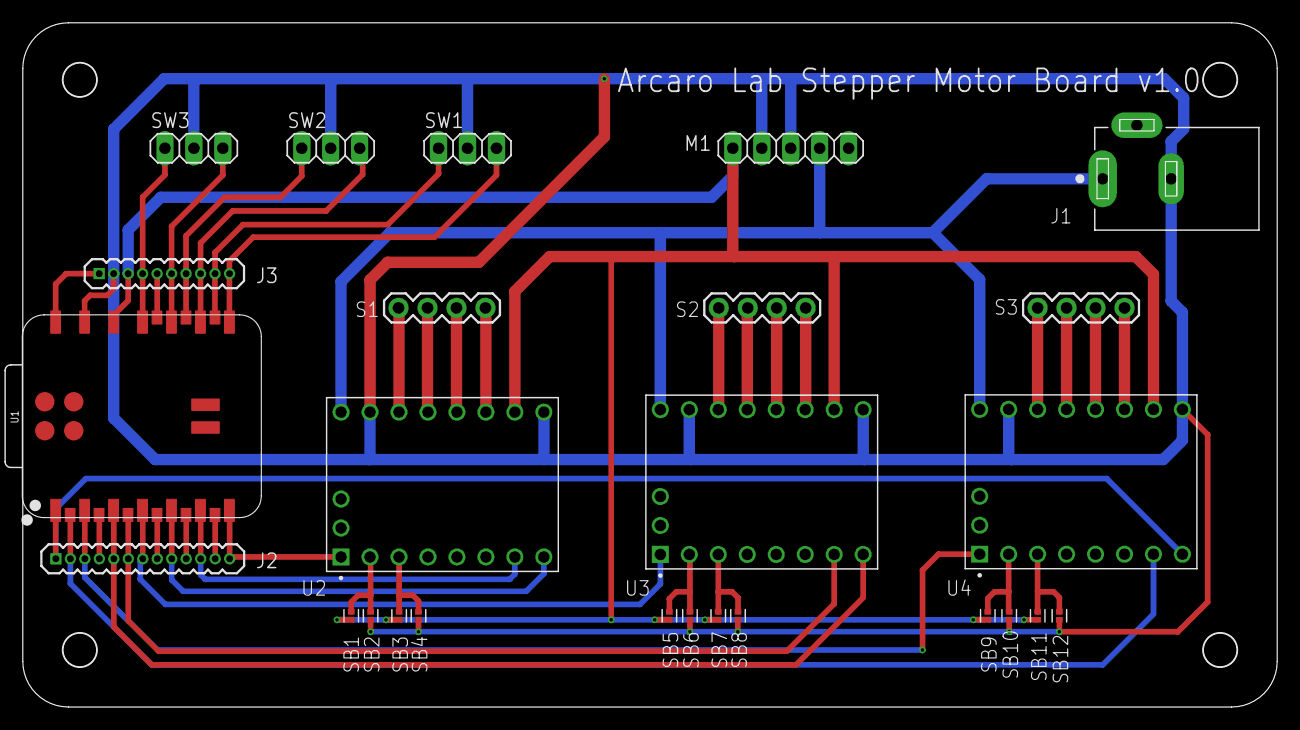
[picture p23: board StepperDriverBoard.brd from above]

Board: 2 copper layers, 110.0 x 60.0 mm, 26 parts (0 on the bottom side), 42 nets.

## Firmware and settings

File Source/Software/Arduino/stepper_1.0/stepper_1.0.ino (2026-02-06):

#include <Arduino.h>
#include <Adafruit_TinyUSB.h>  // OK to keep if your board uses TinyUSB (nRF52 Feather etc.)

// ===================== Pin assignments =====================
// Stepper 1
const int S1_DIR  = D4;
const int S1_STEP = D5;
const int S1_EN   = D6;

// Stepper 2
const int S2_DIR  = D2;
const int S2_STEP = D13;
const int S2_EN   = D3;

// Stepper 3
const int S3_DIR  = D0;
const int S3_STEP = D11;
const int S3_EN   = D1;

// Toggle inputs (active LOW with INPUT_PULLUP)
const int S1_LEFT  = D19;
const int S1_RIGHT = D7;

const int S2_LEFT  = D18;
const int S2_RIGHT = D8;

const int S3_LEFT  = D10;
const int S3_RIGHT = D9;

// ===================== Motion defaults =====================
// steps = number of step pulses
// sp_us = delayMicroseconds used for HIGH and LOW (half-period)
// Example: sp_us=400 => 800us per step => 1250 steps/sec (approx)
int defaultSteps = 100;
int defaultSpUs  = 400;

// ===================== Stepper description table =====================
struct StepperPins {
  int dir;
  int step;
  int en;
};

StepperPins motors[3] = {
  { S1_DIR, S1_STEP, S1_EN },
  { S2_DIR, S2_STEP, S2_EN },
  { S3_DIR, S3_STEP, S3_EN }
};

// ===================== Serial line input buffer =====================
static const size_t LINE_BUF_LEN = 64;
char lineBuf[LINE_BUF_LEN];
size_t lineLen = 0;

// --------------------- Helper: printLine ---------------------
template<typename T, typename... Types>
void printLine(T first, Types... other) {
  Serial.print(first);
  printLine(other...);
}
void printLine() { Serial.println(); }

// --------------------- Stepper low-level helpers ---------------------
void enableMotor(uint8_t idx, bool enable) {
  // Many TMC2209 breakouts use EN as active LOW.
  // Your original code sets EN LOW to enable, so we keep that.
  digitalWrite(motors[idx].en, enable ? LOW : HIGH);
}

void setDir(uint8_t idx, uint8_t dir01) {
  // Match your existing button behavior:
  // RIGHT used DIR=LOW, LEFT used DIR=HIGH.
  // Here: dir=0 (CW) -> LOW, dir=1 (CCW) -> HIGH.
  digitalWrite(motors[idx].dir, (dir01 == 0) ? LOW : HIGH);

  // If you need to flip CW/CCW meaning, swap the LOW/HIGH above.
}

void stepMotor(uint8_t idx, long steps, int sp_us) {
  if (idx >= 3) return;
  if (steps <= 0) return;
  if (sp_us < 2) sp_us = 2; // avoid too-small delays

  // Blocking pulse train (simple + reliable)
  for (long i = 0; i < steps; i++) {
    digitalWrite(motors[idx].step, HIGH);
    delayMicroseconds(sp_us);
    digitalWrite(motors[idx].step, LOW);
    delayMicroseconds(sp_us);
  }
}

// ===================== Serial command parsing =====================
// Supported commands:
//
//   S1,0,100        -> motor 1, dir=0, steps=100 (uses defaultSpUs)
//   S2,1,200,300    -> motor 2, dir=1, steps=200, sp_us=300
//
// Also supports whitespace, and lowercase "s1" etc.

void handleCommand(char* cmd) {
  // Trim leading spaces
  while (*cmd == ' ' || *cmd == '\t' || *cmd == '\r' || *cmd == '\n') cmd++;
  if (*cmd == 0) return;

  // Quick help
  if (strcasecmp(cmd, "HELP") == 0) {
    printLine("Commands:");
    printLine("  S1,0,100         (motor 1, dir 0=CW, steps 100)");
    printLine("  S2,1,200,400     (motor 2, dir 1=CCW, steps 200, sp_us 400)");
    printLine("  POS?             (not implemented here)");
    return;
  }

  // Expect "S<id>,<dir>,<steps>[,<sp_us>]"
  // Example: "S1,0,100"
  if (tolower(cmd[0]) != 's') {
    printLine("ERR: command must start with S (try HELP)");
    return;
  }

  // Parse motor number after 'S'
  int motorId = cmd[1] - '0';   // '1'..'3'
  if (motorId < 1 || motorId > 3) {
    printLine("ERR: motor must be S1..S3");
    return;
  }
  uint8_t idx = (uint8_t)(motorId - 1);

  // Find first comma
  char* p = strchr(cmd, ',');
  if (!p) { printLine("ERR: format S1,dir,steps[,sp_us]"); return; }
  p++; // move past comma

  // Tokenize remaining fields by comma
  // dir
  char* tokDir = p;
  char* tokSteps = strchr(tokDir, ',');
  if (!tokSteps) { printLine("ERR: missing steps"); return; }
  *tokSteps = 0;
  tokSteps++;

  // steps
  char* tokSp = strchr(tokSteps, ',');
  int sp_us = defaultSpUs;
  if (tokSp) {
    *tokSp = 0;
    tokSp++;
    sp_us = atoi(tokSp);
  }

  int dir01 = atoi(tokDir);
  long steps = atol(tokSteps);

  if (!(dir01 == 0 || dir01 == 1)) {
    printLine("ERR: dir must be 0 or 1");
    return;
  }
  if (steps <= 0) {
    printLine("ERR: steps must be > 0");
    return;
  }

  // Execute
  enableMotor(idx, true);
  setDir(idx, (uint8_t)dir01);
  stepMotor(idx, steps, sp_us);

  printLine("OK: S", motorId, " dir=", dir01, " steps=", steps, " sp_us=", sp_us);
}

// Read serial bytes into a line buffer; process on newline
void pollSerial() {
  while (Serial.available()) {
    char c = (char)Serial.read();

    // End of line -> process
    if (c == '\n' || c == '\r') {
      if (lineLen > 0) {
        lineBuf[lineLen] = 0;  // null-terminate
        handleCommand(lineBuf);
        lineLen = 0;
      }
      continue;
    }

    // Normal char
    if (lineLen < (LINE_BUF_LEN - 1)) {
      lineBuf[lineLen++] = c;
    } else {
      // overflow: reset
      lineLen = 0;
      printLine("ERR: line too long");
    }
  }
}

// ===================== Setup / Loop =====================
void setup() {
  Serial.begin(57600);
  while (!Serial) { delay(10); }

  pinMode(LED_RED, OUTPUT);
  digitalWrite(LED_RED, LOW);

  // Motor pins
  for (int i = 0; i < 3; i++) {
    pinMode(motors[i].dir, OUTPUT);
    pinMode(motors[i].step, OUTPUT);
    pinMode(motors[i].en, OUTPUT);

    // Enable by default (your original behavior)
    enableMotor(i, true);
  }

  // Buttons
  pinMode(S1_LEFT,  INPUT_PULLUP);
  pinMode(S1_RIGHT, INPUT_PULLUP);
  pinMode(S2_LEFT,  INPUT_PULLUP);
  pinMode(S2_RIGHT, INPUT_PULLUP);
  pinMode(S3_LEFT,  INPUT_PULLUP);
  pinMode(S3_RIGHT, INPUT_PULLUP);

  printLine("Started. Type HELP. Serial format: S1,0,100 or S2,1,200,400");
}

void loop() {
  pollSerial();

  // ---------- Existing button behavior ----------
  if (digitalRead(S1_LEFT) == LOW) {
    digitalWrite(motors[0].dir, HIGH);
    stepMotor(0, defaultSteps, defaultSpUs);
    printLine("BTN: S1_LEFT");
  } else if (digitalRead(S1_RIGHT) == LOW) {
    digitalWrite(motors[0].dir, LOW);
    stepMotor(0, defaultSteps, defaultSpUs);
    printLine("BTN: S1_RIGHT");
  }

  if (digitalRead(S2_LEFT) == LOW) {
    digitalWrite(motors[1].dir, HIGH);
    stepMotor(1, defaultSteps, defaultSpUs);
    printLine("BTN: S2_LEFT");
  } else if (digitalRead(S2_RIGHT) == LOW) {
    digitalWrite(motors[1].dir, LOW);
    stepMotor(1, defaultSteps, defaultSpUs);
    printLine("BTN: S2_RIGHT");
  }

  if (digitalRead(S3_LEFT) == LOW) {
    digitalWrite(motors[2].dir, HIGH);
    stepMotor(2, defaultSteps, defaultSpUs);
    printLine("BTN: S3_LEFT");
  } else if (digitalRead(S3_RIGHT) == LOW) {
    digitalWrite(motors[2].dir, LOW);
    stepMotor(2, defaultSteps, defaultSpUs);
    printLine("BTN: S3_RIGHT");
  }
}

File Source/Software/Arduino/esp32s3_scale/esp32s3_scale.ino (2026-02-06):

/*
  ESP32-S3 TFT Feather (Reverse) + NAU7802 load cell scale
  --------------------------------------------------------
  Replacement for Teensy 3.2 + TeensyView + TeensyLoadcell project.

  Features
  - Reads NAU7802 ADC (I2C) connected to a 1 kg load cell / bridge
  - Converts to grams using a simple linear calibration (tare offset + scale factor)
  - Displays current weight and max weight on the built-in TFT
  - Prints weight to Serial
  - Tare with:
      * Button on D1 (active-high, uses INPUT_PULLDOWN)
      * Serial command 't'
  - Start/stop streaming with Serial command 's' (like the Teensy sketch)

  Libraries
  - Adafruit_NAU7802
  - Adafruit_GFX
  - Adafruit_ST7789

  Calibration (IMPORTANT)
  1) Upload & open Serial Monitor.
  2) With nothing on the scale, press the D1 button (or send 't') to tare.
  3) Put a known weight (e.g. 100 g) on the scale.
  4) Read the printed "RAW" and "TARE" values and compute:

        scale_g_per_count = known_grams / (raw_with_weight - tare_raw)

     Put that value into CAL_G_PER_COUNT below.

  Notes
  - This code intentionally keeps calibration simple and transparent.
  - If you see negative values due to wiring polarity, either swap the load cell
    signal wires OR leave as-is and the code will absolute-value the reading.

*/

#include <Adafruit_NAU7802.h>

#include <Adafruit_GFX.h>     // Core graphics library
#include <Adafruit_ST7789.h>  // Hardware-specific library for ST7789
#include <SPI.h>
#include <Wire.h>

// TFT: the Feather TFT examples use these board-defined macros (TFT_CS, TFT_DC, TFT_RST, etc.)
Adafruit_ST7789 tft = Adafruit_ST7789(TFT_CS, TFT_DC, TFT_RST);

// NAU7802
Adafruit_NAU7802 nau;

// --- User settings ---
static const uint32_t SERIAL_BAUD = 115200;

// Tare button (D1)
#ifndef PIN_TARE
#define PIN_TARE 1
#endif

// Display update period (ms)
static const uint32_t UI_PERIOD_MS = 100;

// Serial update period (ms)
static const uint32_t SERIAL_PERIOD_MS = 200;  // 5 Hz
static uint32_t last_serial_ms = 0;

// Smoothing (0 = no smoothing, closer to 1 = heavier smoothing)
// Original Teensy code used tau=0.2; this is "similar feel" in a simple EMA.
static const float EMA_ALPHA = 0.20f;

// Calibration parameters
// Set after you do the quick calibration procedure in the header comment.
static float CAL_G_PER_COUNT = 0.0009352f;// 0.000100f;  // <-- placeholder, must be tuned
static int32_t tare_raw = 0;

// --- State ---
static bool isRunning = true;
static float weight_g_filt = 0.0f;
static float max_g = 0.0f;

static uint32_t last_ui_ms = 0;

// ---------- Helpers ----------
static void tftHeader() {
  tft.fillScreen(ST77XX_BLACK);
  tft.setRotation(3);

  // tft.setTextWrap(false);
  // tft.setTextColor(ST77XX_WHITE);
  // tft.setTextSize(2);
  // tft.setCursor(0, 0);
  // tft.print("Digital Scale");

  tft.setTextSize(1);
  tft.setCursor(0, 5);
  tft.print("D1: tare | Serial: 't' tare");
}

static void drawValuesFast(float g_now, float g_max) {
  // Use background color to overwrite previous text (no fillRect)
  tft.setTextWrap(false);

  // Line 1
  tft.setCursor(0, 50);
  tft.setTextSize(3);
  tft.setTextColor(ST77XX_WHITE, ST77XX_BLACK);
  tft.print("Weight: ");
  char buf[16];
  snprintf(buf, sizeof(buf), "%4dg", (int)lroundf(g_now));  // pad spaces!
  tft.print(buf);

  // Line 2
  tft.setCursor(0, 95);
  tft.setTextSize(3);
  tft.setTextColor(ST77XX_WHITE, ST77XX_BLACK);
  tft.print("Max:    ");
  snprintf(buf, sizeof(buf), "%4dg", (int)lroundf(g_max));
  tft.print(buf);
}


static int32_t readRawBlocking() {
  while (!nau.available()) {
    delay(1);
  }
  return nau.read();
}

static int32_t readRawAverage(uint8_t n) {
  int64_t acc = 0;
  for (uint8_t i = 0; i < n; i++) {
    acc += readRawBlocking();
  }
  return (int32_t)(acc / n);
}

static void tareNow() {
  // Take a small average for a stable tare
  tare_raw = readRawAverage(20);
  weight_g_filt = 0.0f;
  max_g = 0.0f;

  Serial.print("TARE set. tare_raw=");
  Serial.println(tare_raw);
}

static float rawToGrams(int32_t raw) {
  // Convert raw reading to grams
  float g = (float)(raw - tare_raw) * CAL_G_PER_COUNT;

  // Match original Teensy behavior: show absolute weight
  if (g < 0) g = -g;
  return g;
}

static bool tareButtonPressedDebounced() {
  // Simple debounce: detect stable low for ~30 ms
  static uint8_t stableCount = 0;
  if (digitalRead(PIN_TARE) == HIGH) {
    if (stableCount < 6) stableCount++;
  } else {
    stableCount = 0;
  }
  return (stableCount >= 6);
}

// ---------- Setup ----------
void setup() {
  Serial.begin(SERIAL_BAUD);
  delay(50);

  // Button
  pinMode(PIN_TARE, INPUT_PULLDOWN);

  // TFT backlight and power rails (from Adafruit Feather TFT example)
  pinMode(TFT_BACKLITE, OUTPUT);
  digitalWrite(TFT_BACKLITE, HIGH);

  pinMode(TFT_I2C_POWER, OUTPUT);
  digitalWrite(TFT_I2C_POWER, HIGH);
  delay(10);

  // TFT init
  tft.init(135, 240);         // ST7789 240x135'
  tft.setSPISpeed(80000000);  // 40 MHz
  tftHeader();


  // I2C for NAU7802
  Wire.begin();

  Serial.println();
  Serial.println("ESP32-S3 Scale + NAU7802");
  Serial.println("Commands: 't' tare, 's' start/stop");
  Serial.println("Tip: Calibrate CAL_G_PER_COUNT in the sketch header.");

  if (!nau.begin()) {
    Serial.println("ERROR: Failed to find NAU7802. Check wiring/I2C power.");
    tft.fillScreen(ST77XX_BLACK);
    tft.setCursor(0, 0);
    tft.setTextSize(2);
    tft.setTextColor(ST77XX_RED);
    tft.println("NAU7802 not found");
    while (1) delay(10);
  }
  Serial.println("Found NAU7802");


  // Configure NAU7802 similar to your example
  nau.setLDO(NAU7802_3V0);
  nau.setGain(NAU7802_GAIN_128);
  nau.setRate(NAU7802_RATE_320SPS);

  // Flush initial readings
  for (uint8_t i = 0; i < 10; i++) (void)readRawBlocking();

// Calibrate internal + offset
lead:
  while (!nau.calibrate(NAU7802_CALMOD_INTERNAL)) {
    Serial.println("Failed internal offset cal, retrying...");
    delay(200);
  }
  while (!nau.calibrate(NAU7802_CALMOD_OFFSET)) {
    Serial.println("Failed system offset cal, retrying...");
    delay(200);
  }
  Serial.println("NAU7802 calibrated");

  // Initial tare
  delay(300);
  tareNow();

  last_ui_ms = millis();
}
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

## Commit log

2025-03-05 Initial Commit
    Create project for ShrewBox Design
    [BackPanel.dxf, BillOfMaterials_v1.xlsx, BottomGuide.dxf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]
2025-03-06 Updated BOM and added 3D file for Carriage
    [BillOfMaterials_v1.xlsx, Carriage.stl]
2025-09-09 Create BillOfMaterials_v2.xlsx
    Added materials for new pump
    [BillOfMaterials_v2.xlsx]
2026-02-04 Update files for syringe pump, panels. Added PCB files for Stepper Driver
    [BackPanel.dxf, BillOfMaterials_v1.xlsx, BillOfMaterials_v2.xlsx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]
2026-02-05 Corrected the thickness of Acrylic Sheets in BOM
    [BillOfMaterials_v2.xlsx]
2026-02-06 Updated stepper and scale software
2026-06-25 Updated LaserCutPanels
    Enlarged the EBox
    Shorten the WeightFloor
    Corrected BottomGuide
    [BottomGuide.dxf, EBoxBottomPanel.dxf, EBoxFrontPanel.dxf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]
2026-06-30 Update GuardPanel.dxf
    Make GuardPanel fit into 12 inch acrylic sheet
    [GuardPanel.dxf]
